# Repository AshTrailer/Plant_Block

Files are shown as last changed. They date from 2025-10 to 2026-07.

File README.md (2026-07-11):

# Plant Block - 智能植物养护系统 / Intelligent Plant Care System

[]()
[]()
[]()
[]()

基于 ESP32 的环境监测与自动控制系统，支持通风、补光、TEC 温控、浇水等核心功能，具备本地串口调试、云端 MQTT 远程监控能力。

*An ESP32-based environmental monitoring and automatic control system, supporting ventilation, supplemental lighting, TEC temperature control, watering, and other core functions, with local serial debugging and cloud MQTT remote monitoring capabilities.*

---

## 项目升级日志 / Project Update Log

### 🔧 最新更新 — 第二版原理图设计完成 / Latest: v2.0 Schematic Design Completed

第二版原理图绘制、焊盘及封装绘制已全部完成。电源架构与功能模块方案已最终确定，详见下方第二版硬件设计章节。PCB 布局布线为下一阶段工作。

*The v2.0 schematic, footprint, and PCB library have been completed. The power architecture and functional module design have been finalized — see the v2.0 hardware design section below. PCB layout is the next phase.*

### 2026年4月15日更新 — 第二版开发预告 / Apr 15, 2026 — v2.0 Development Preview

第二版硬件规划启动，将进行多项重大升级，提升系统性能和扩展性。

*v2.0 hardware planning initiated, featuring major upgrades to improve system performance and scalability.*

### 2026年3月更新 — 第一版完成 / Mar 2026 — v1.0 Completed

第一版硬件已完成设计、打样，软件核心功能开发完毕，升级为 4 通道版本。

*v1.0 hardware design, fabrication, and core software development completed; upgraded to a 4-channel version.*

---

## 第一版硬件设计 (v1.0) / v1.0 Hardware Design

> **设计思路 / Design Philosophy**：第一版以"多通道独立控制"为核心，目标是同时管理 4 个独立植物模块，每个模块配备独立的 LED 补光与传感器接口。12V 供电、单级降压的简洁架构便于快速验证核心功能。

> *v1.0 centered on "multi-channel independent control," aiming to manage 4 separate plant modules simultaneously, each with independent LED lighting and sensor interfaces. The simple 12V single-stage buck architecture enabled rapid core functionality validation.*

### 硬件架构 / Hardware Architecture

#### 电源系统 / Power System输入 / Input：12V DC
├── TPS54302DDCR：12V → 5V 降压转换 / Buck Converter\
├── PT4115：LED 恒流驱动 ×4 / Constant Current LED Driver ×4\
└── 各模块供电分配 / Peripheral Power Distribution

#### 控制通道配置 / Control Channel Configuration

| 模块类型 / Module Type | 设计预留 / Designed | 实际可用 / Available | 原因说明 / Note |
|---|---|---|---|
| **光照控制 / Lighting** | 4 通道 / ch | 4 通道 / ch | 每通道 3W，总计 12W / 3W per ch, 12W total |
| **水泵控制 / Water Pump** | 4 个 | 1 个 | PCB GPIO 端口分配错误 / GPIO assignment error |
| **传感器接口 / Sensor** | 4 个 | 1 个 | PCB GPIO 端口分配错误 / GPIO assignment error |

#### 核心功能模块 / Core Functional Modules

| # | 模块 / Module | 说明 / Description |
|---|---|---|
| 1 | **通风控制 / Ventilation** | 定时启停风扇 / Timed fan on/off |
| 2 | **补光灯控制 / Lighting** | PWM 智能调光（自动渐亮/渐暗）/ PWM dimming with auto fade |
| 3 | **LED 散热控制 / LED Cooling** | 独立散热管理 / Independent thermal management |
| 4 | **智能浇水 / Watering** | 土壤湿度阈值、4 小时防重复、周计划管理 / Soil moisture threshold, 4h anti-repeat, weekly schedule |
| 5 | **时间管理 / Time** | 软件计时、Unix 时间戳、ISO 周数、星期计算 / Software timer, Unix timestamp, ISO week, weekday calc |
| 6 | **命令解析器 / CLI** | 非阻塞串口命令，完整调试接口 / Non-blocking serial command parser |
| 7 | **云端通信 / Cloud** | WiFi + MQTT over TLS（状态上报、远程命令、遗嘱消息）/ Status report, remote command, LWT |
| 8 | **数据处理 / Data** | 去极值、均值、标准差、稳定性判断 / Outlier removal, mean, stddev, stability check |

> **注 / Note**：串口屏交互功能暂未开发，将在后续版本中实现。
> *The serial touchscreen UI is not yet developed and will be implemented in a future version.*

#### 硬件图片 / Hardware Images

<div align="center">
  v1.0 PCB Front / 第一版电路板正面
  <br/><em>第一版电路板正面 / v1.0 PCB Front View</em>
</div>

<div align="center">
  System Block Diagram / 系统框图
  Electrical Components / 电气组件图
  <br/><em>左：系统框图 / Left: System Block Diagram &nbsp;|&nbsp; 右：电气组件图 / Right: Electrical Components</em>
</div>

#### 第一版小结 / v1.0 Summary

| 维度 / Aspect | 状态 / Status |
|---|---|
| **硬件 / Hardware** | Cadence 原理图、封装、初版 PCB 已完成并打样，等待测试 / Schematic, footprint, PCB designed & fabricated, awaiting test |
| **软件 / Software** | 核心功能已完成，升级为 4 通道版本 / Core functions complete, 4-channel support |
| **已知问题 / Known Issues** | GPIO 端口分配错误导致部分通道不可用；12V 供电限制了 TEC 等大功率模块的引入 / GPIO assignment errors; 12V limits high-power modules like TEC |

---

## 第二版硬件设计 (v2.0) / v2.0 Hardware Design

> **设计思路 / Design Philosophy**：第二版从"多通道简单控制"转向"单系统精细化控制"。核心变化包括：① 提升输入电压至 24V 以支持更大功率负载；② 引入 TEC 半导体制冷实现主动温控；③ 使用 50W COB 灯珠替代 4 颗分立 LED，简化光路并提升光效；④ 增加多种传感器实现全方位环境感知；⑤ 增加硬件级过温保护，提升系统安全性。

> *v2.0 shifts from "multi-channel simple control" to "single-system precision control." Key changes: ① 24V input to support higher power loads; ② TEC-based active cooling; ③ 50W COB LED replaces 4 discrete LEDs for simplified optics and higher efficiency; ④ multi-sensor fusion for comprehensive environmental awareness; ⑤ hardware-level over-temperature protection for improved safety.*

---

### 2.1 电源架构 / Power Architecture

#### 电源树 / Power Tree
24V DC 输入 / Input\
│\
├── [保护电路 / Protection]\
│   ├── 防反接 / Reverse Polarity Protection\
│   ├── 防静电 (ESD) / ESD Protection\
│   └── 防浪涌 / Surge Protection\
│\
├── TPS56A37 ────────────► 12V @ 3A+ ────┬── 蠕动泵 / Peristaltic Pump (SI2302)\
│   (24V → 12V Buck)                      ├── TEC 冷端风扇 / TEC Cold-side Fan (SI2302)\
│                                         ├── 通风风扇 / Ventilation Fan (SI2302)\
│                                         └── 水冷风扇 / Water-cooling Fan (SI2302)\
│\
├── TPS54302DDCR ────────► 5V @ 2A+ ────┬── ESP32-WROOM-32E-N8(24V → 5V Buck)\
│                                       ├── CH340C (USB-UART)\
│                                       ├── DS18B20 ×2 (One Wire)\
│                                       ├── SHT30 (I²C)\
│                                       ├── 浮球开关 / Float Switch\
│                                       ├── IR2104STRPBF ×2 (TEC 半桥驱动)\
│                                       └── LM393DT ×2 (PT100 比较器)\
│\
└── AMS1117-3V3 ─────────► 3.3V ────────► ESP32 内核及 GPIO / ESP32 Core & GPIO
(5V → 3.3V LDO)

#### 电源芯片选型对比 / Power IC Selection

| 功能 / Function | 芯片 / IC | 输入范围 / Input | 输出 / Output | 说明 / Note |
|---|---|---|---|---|
| 24V → 12V Buck | **TPS56A37** | 4.5V – 28V | 12V / 3A+ | 同步降压，高效率 / Synchronous buck, high efficiency |
| 24V → 5V Buck | **TPS54302DDCR** | 4.5V – 28V | 5V / 2A+ | 与第一版同型号，输入范围满足 24V / Same IC as v1.0, input range covers 24V |
| 5V → 3.3V LDO | **AMS1117-3V3** | up to 15V | 3.3V / 1A | 经典低压差线性稳压器 / Classic low-dropout regulator |

#### 保护电路详情 / Protection Circuit Details

| 保护类型 / Protection | 实现方式 / Implementation | 防护对象 / Target |
|---|---|---|
| **防反接 / Reverse Polarity** | PMOS / 肖特基二极管方案 | 全部后端电路 / All downstream circuits |
| **防静电 / ESD** | TVS 二极管阵列（24V 输入端 + USB 信号线） | 电源入口及敏感信号引脚 |
| **防浪涌 / Surge** | TVS 管 + 共模电感 + π 型滤波 | 电源入口，抑制瞬态过压 |

---

### 2.2 功能模块详述 / Functional Modules

#### 2.2.1 蠕动泵控制 / Peristaltic Pump Control

| 参数 / Parameter | 规格 / Specification |
|---|---|
| **供电电压 / Voltage** | 12V DC |
| **驱动方式 / Drive** | **SI2302** N-MOSFET 低端开关 / Low-side switch |
| **控制接口 / Control** | ESP32 GPIO → SI2302 Gate（带栅极下拉电阻 / with gate pull-down） |
| **PWM 调速** | 支持 / Supported（软件可调流量 / software-adjustable flow rate） |
| **续流保护 / Flyback** | 肖特基二极管并联泵电机 / Schottky diode across pump motor |

#### 2.2.2 风扇控制（3 路）/ Fan Control (3 Channels)

三路风扇均采用统一驱动方案，仅控制 GPIO 不同：

*All 3 fan channels use the same driver topology with different control GPIOs:*

| 风扇 / Fan | 用途 / Purpose | 供电 / Voltage | 驱动 MOSFET |
|---|---|---|---|
| **TEC 冷端风扇** / Cold-side Fan | 为 TEC 冷端散热器强制通风 / Force air over TEC cold-side heatsink | 12V | SI2302 |
| **通风风扇** / Ventilation Fan | 培养空间空气交换 / Grow space air exchange | 12V | SI2302 |
| **水冷风扇** / Water-cooling Fan | TEC 热端水冷排散热 / Radiator cooling for TEC hot-side | 12V | SI2302 |

#### 2.2.3 浮球开关 / Float Switch (液位检测 / Water Level Detection)

| 参数 / Parameter | 规格 / Specification |
|---|---|
| **类型 / Type** | 机械浮球开关 / Mechanical float switch（常开/常闭可选 / NO/NC selectable） |
| **接口 / Interface** | GPIO 数字输入 + 上拉电阻 / GPIO digital input with pull-up |
| **功能 / Function** | 水箱低液位检测，防止泵空转 / Low water level detection to prevent pump dry-running |
| **软件处理 / Software** | 低液位触发中断 → 停止蠕动泵 + MQTT 报警 / Low level interrupt → stop pump + MQTT alert |

#### 2.2.4 DS18B20 温度传感器 ×2 / Dual DS18B20 Temperature Sensors

| 参数 / Parameter | 规格 / Specification |
|---|---|
| **总线类型 / Bus** | **One Wire（单总线）**，两颗传感器共享同一 GPIO / Shared single GPIO |
| **传感器 1** | TEC 冷端温度 / TEC cold-side temperature |
| **传感器 2** | TEC 热端温度 / TEC hot-side temperature |
| **分辨率 / Resolution** | 9–12 bit 可配置 / configurable（默认 12 bit / default 12 bit） |
| **供电方式 / Power** | 寄生供电模式 / Parasite power mode（VDD 接 GND）或外部供电 |
| **识别方式 / ID** | 通过唯一 64-bit ROM ID 区分两颗传感器 / Distinguished by unique 64-bit ROM ID |

> **设计说明 / Design Note**：两颗 DS18B20 共享单个 GPIO 可节省 ESP32 引脚资源。软件通过 ROM ID 分别读取冷端和热端温度，用于 TEC PID 控制算法的反馈输入。
> *Sharing a single GPIO conserves ESP32 pins. Firmware distinguishes sensors by ROM ID for cold/hot side temperature feedback into the TEC PID control loop.*

#### 2.2.5 SHT30 温湿度传感器 / SHT30 Temperature & Humidity Sensor

| 参数 / Parameter | 规格 / Specification |
|---|---|
| **芯片 / IC** | SHT30-DIS（I²C 接口） |
| **测量范围 / Range** | 温度 / Temp：-40°C ~ +125°C；湿度 / Humidity：0% ~ 100% RH |
| **精度 / Accuracy** | 温度 / Temp：±0.3°C；湿度 / Humidity：±2% RH（典型值 / typical） |
| **接口 / Interface** | I²C（SCL + SDA），3.3V 供电 |
| **用途 / Purpose** | 培养空间环境温湿度监测 / Ambient temp & humidity monitoring in grow space |

#### 2.2.6 50W COB 灯珠驱动 / 50W COB LED Driver

| 参数 / Parameter | 规格 / Specification |
|---|---|
| **LED 类型 / Type** | 50W COB（Chip-on-Board）灯珠，全光谱 / Full-spectrum |
| **驱动芯片 / Driver IC** | **XL6005E1** — Boost 升压恒流驱动 / Boost constant-current driver |
| **调光方式 / Dimming** | **PWM 调光**，ESP32 GPIO 输出 PWM 至 XL6005E1 EN/DIM 引脚 |
| **调光频率 / PWM Freq** | 建议 1kHz – 20kHz（避开人耳敏感频段 / avoid audible range） |
| **散热策略 / Cooling** | COB 灯珠独立散热片 + 通风风扇辅助 / Dedicated heatsink + ventilation fan |

> **设计说明 / Design Note**：相比第一版的 4 路 PT4115 + 3W 分立 LED，第二版采用单颗 50W COB + XL6005E1 Boost 方案。优势：① 光效更高；② 光谱均匀性更好；③ 简化 PCB 布线（单通道 vs 四通道）；④ 减少元器件数量。
> *Compared to v1.0's 4× PT4115 + 3W discrete LEDs, v2.0 uses a single 50W COB + XL6005E1 boost topology. Advantages: higher efficacy, better spectral uniformity, simplified PCB routing (1ch vs 4ch), and reduced BOM count.*

#### 2.2.7 TEC H 桥控制电路 / TEC H-Bridge Control

这是第二版最核心的新增模块，用于驱动 TEC 半导体制冷片实现双向温控（加热/制冷）。

*This is the most critical new module in v2.0, driving the TEC (Peltier) module for bidirectional temperature control (heating/cooling).*

| 组件 / Component | 型号 / Part | 数量 / Qty | 功能 / Function |
|---|---|---|---|
| **TEC 模块 / TEC Module** | TEC1-12706 | 1 | 12V / 6A max，实际 ≤3A |
| **半桥驱动 / Half-bridge Driver** | **IR2104STRPBF** | 2 | 自举高侧驱动 / Bootstrap high-side driver |
| **H 桥 MOSFET** | **IRFZ44NS** | 4 | N-MOSFET，55V/49A，低 Rds(on) |
| **自举电容 / Bootstrap Cap** | 10µF–22µF 瓷片 | 2 | 为高侧 MOSFET 提供栅极驱动电压 |
| **自举二极管 / Bootstrap Diode** | 快恢复二极管 / Fast recovery | 2 | 自举电容充电通路 |

| 设计要点 / Design Point | 详情 / Detail |
|---|---|
| **死区时间 / Dead Time** | 软件控制，防止上下管直通 / Software-controlled to prevent shoot-through |
| **开关频率 / Switching Freq** | 建议 20kHz–50kHz PWM / Recommended 20kHz–50kHz PWM |
| **仿真验证 / Simulation** | 已通过 **LTspice** 仿真验证 H 桥开关波形及自举电路工作正常 |
| **电流采样 / Current Sense** | 可选：H 桥低端串联采样电阻 + 差分放大器 → ESP32 ADC |

> **LTspice 仿真已通过** — H 桥开关时序、自举电容充放电、死区保护逻辑均已仿真验证。
> *LTspice simulation passed — H-bridge switching timing, bootstrap capacitor charging, and dead-time protection have been verified.*

#### 2.2.8 PT100 过温断电电路 / PT100 Over-Temperature Shutdown

独立于 MCU 的硬件级过温保护，当 TEC 或 COB LED 区域温度异常升高时自动切断电源。

*Hardware-level over-temperature protection independent of the MCU — automatically cuts power if TEC or COB LED area temperature rises abnormally.*

| 组件 / Component | 型号 / Part | 数量 / Qty | 功能 / Function |
|---|---|---|---|
| **温度传感器 / Temp Sensor** | PT100 铂电阻 / Platinum RTD | 1 | 温度 → 电阻变化 / Temperature → resistance |
| **比较器 / Comparator** | **LM393DT** | 2 | 双路比较器，提供窗口比较 / Dual comparator for window comparison |
| **基准电压 / Reference** | 电阻分压或 TL431 | 1 | 设定过温阈值 / Sets over-temp threshold |

Q1/Q3 由 IR2104 #1 驱动 / driven by IR2104 #1
Q2/Q4 由 IR2104 #2 驱动 / driven by IR2104 #2

方向控制 / Direction Control:

Q1+Q4 导通 → TEC 正向电流 → 制冷模式 / Cooling
Q2+Q3 导通 → TEC 反向电流 → 加热模式 / Heating
PWM 占空比调节 → 功率控制 / Power modulation
PT100 过温断电电路原理 / Over-Temp Shutdown Principle:

PT100 ──► 惠斯通电桥 / Wheatstone Bridge ──► LM393DT #1 (上限比较 / Upper threshold)
──► LM393DT #2 (下限比较 / Lower threshold)
│
比较器输出 / Comparator Out ──► MOSFET 切断主电源
Cut main power via MOSFET

| 设计要点 / Design Point | 详情 / Detail |
|---|---|
| **阈值设定 / Threshold** | 通过分压电阻设定，如 80°C 触发断电 / Set via resistor divider, e.g., 80°C trip point |
| **滞回 / Hysteresis** | 正反馈电阻实现滞回，防止临界温度反复开关 / Positive feedback resistor prevents oscillation near threshold |
| **独立性 / Independence** | 纯硬件电路，ESP32 死机/复位不影响保护功能 / Pure hardware — protection works even if ESP32 crashes |
| **输出 / Output** | 比较器输出驱动 MOSFET 或继电器切断 24V 主干路 |

#### 2.2.9 MCU 及编程接口 / MCU & Programming Interface

| 参数 / Parameter | 规格 / Specification |
|---|---|
| **主控 / MCU** | **ESP32-WROOM-32E-N8**（8MB Flash，WiFi + BLE） |
| **USB 转串口 / USB-UART** | **CH340C** |
| **USB 接口 / USB Connector** | **USB-C**（支持烧录与串口通信 / programming & serial） |
| **自动下载电路 / Auto-Download** | EN + IO0 自动时序控制（DTR/RTS → 三极管/MOSFET） |
| **备用烧录 / Alt Programming** | 排母/排针引出 TX/RX/EN/IO0/GND，可外接 USB-UART 模块 |
| **按键 / Buttons** | RESET + BOOT（IO0）按键，支持手动进入下载模式 |
自动下载电路原理 / Auto-Download Circuit:

CH340C DTR ──► 电容耦合 ──► ESP32 EN
CH340C RTS ──► 电容耦合 ──► ESP32 IO0

当 esptool/platformio 发起下载时，DTR/RTS 自动产生复位 + 进入下载模式的时序。
When esptool/platformio initiates flashing, DTR/RTS automatically generate
the reset + bootloader entry timing sequence.

---

### 2.3 原理图 / Schematics

#### 原理图一：电源架构及外设模块 / Schematic 1: Power Architecture& Peripherals

> **涵盖内容 / Coverage**：24V DC 输入保护（防反接/ESD/浪涌）→ TPS56A37 (24V→12V) → TPS54302DDCR (24V→5V) → AMS1117-3V3 (5V→3.3V)，各电压轨去耦电容及测试点。DS18B20 ×2 (One Wire) + SHT30 (I²C) + 浮球开关 + SI2302 ×4 (蠕动泵/3路风扇) + XL6005E1 COB LED 驱动

> *24V DC input protection (reverse polarity / ESD / surge) → TPS56A37 (24V→12V) → TPS54302DDCR (24V→5V) → AMS1117-3V3 (5V→3.3V), decoupling capacitors and test points for each rail.DS18B20 ×2 (One Wire) + SHT30 (I²C) + float switch + SI2302 ×4 (pump / 3× fans) + XL6005E1 COB LED driver.*

<div align="center">



*原理图一：电源架构及外设模块 / Schematic 1: Power Architecture& Peripherals*

</div>

---


#### 原理图二：主控及TEC H 桥及过温保护 / Schematic 2: MCU & TEC H-Bridge & Over-Temp Protection

> **涵盖内容 / Coverage**：ESP32-WROOM-32E-N8 + CH340C + USB-C + 自动下载电路 + 按键电路 + IR2104STRPBF ×2 半桥驱动 + IRFZ44NS ×4 H 桥 MOSFET + TEC 接口 + 自举电路 + PT100 惠斯通电桥 + LM393DT ×2 窗口比较器 + 过温断电输出。

> *ESP32-WROOM-32E-N8 + CH340C + USB-C + auto-download circuit + buttons + IR2104STRPBF ×2 half-bridge drivers + IRFZ44NS ×4 H-bridge MOSFETs + TEC connector + bootstrap circuits + PT100 Wheatstone bridge + LM393DT ×2 window comparator + over-temp shutdown output.*

<div align="center">

*原理图二：主控及TEC H 桥及过温保护 / Schematic 2: MCU & TEC H-Bridge & Over-Temp Protection*

</div>

---

#### 原理图三：接口 / Schematic 3: Connector

> **涵盖内容 / Coverage**：各级接口。

> *Various of Connectors*

<div align="center">



*原理图三：接口 / Schematic 3: Connector*

</div>

---

### 2.4 第一版 → 第二版 设计演进对比 / v1.0 → v2.0 Design Evolution

以下对比表清晰展示了两个版本之间的设计思路变化：

*The following comparison clearly illustrates the design evolution between the two versions:*

| 维度 / Aspect | 第一版 v1.0 | 第二版 v2.0 | 变化说明 / Note |
|---|---|---|---|
| **输入电源 / Input** | 12V DC / 5A | **24V DC / 5A** | 提升电压减少电流损耗，适配 TEC 等大功率负载 |
| **电压轨 / Rails** | 12V → 5V（单级） | 24V → 12V → 5V → 3.3V（三级） | 分级供电，各电压轨独立稳压 |
| **24V→12V Buck** | — | **TPS56A37** | 新增，为 12V 设备供电 |
| **24V→5V Buck** | TPS54302DDCR (12V→5V) | **TPS54302DDCR** (24V→5V) | 同芯片，输入范围满足 24V |
| **5V→3.3V LDO** | — | **AMS1117-3V3** | 新增，ESP32 独立 3.3V 供电 |
| **输入保护 / Protection** | 基本 / Basic | **防反接 + ESD + 浪涌** | 全面提升可靠性 |
| **LED 照明 / Lighting** | 4× 3W 分立 LED + PT4115 | **1× 50W COB + XL6005E1** | 集成化、高光效、PWM 调光 |
| **TEC 温控 / TEC** | 无 / None | **TEC1-12706 + H 桥** | 核心新增功能，主动制冷/加热 |
| **H 桥驱动 / H-Bridge** | — | **IR2104STRPBF ×2 + IRFZ44NS ×4** | LTspice 仿真验证 |
| **过温保护 / OT Protection** | 无 / None | **PT100 + LM393DT ×2** | 硬件级独立保护 |
| **温度传感器 / Temp Sensor** | — | **DS18B20 ×2** (One Wire 共享 GPIO) | TEC 冷端 & 热端双点监测 |
| **温湿度传感器 / RH Sensor** | — | **SHT30** (I²C) | 环境温湿度监测 |
| **液位检测 / Water Level** | — | **浮球开关** | 水箱液位，防泵空转 |
| **水泵 / Pump** | 普通水泵（1 路可用） | **蠕动泵** (SI2302 驱动) | 更精确的流量控制 |
| **风扇控制 / Fan** | 通风风扇 | **3 路** (TEC冷端+通风+水冷) | 全部 12V / SI2302 NMOS |
| **MCU / 主控** | ESP32 | **ESP32-WROOM-32E-N8** | 8MB Flash，性能更稳定 |
| **USB 接口 / USB** | Micro-USB | **USB-C + CH340C** | 正反插，更可靠 |
| **自动下载 / Auto-DL** | 基础 / Basic | **DTR/RTS 自动下载电路** | 一键烧录 |
| **烧录方式 / Programming** | USB | **USB-C + 排母/排针** | 双通道烧录 |
| **PCB 层数 / PCB Layers** | 2 层 | **规划 4 层** | 改善信号完整性和 EMC |
| **软件适配 / Software** | 4 通道架构 | 需适配新硬件驱动 | TEC PID、多传感器融合等 |

---

### 2.5 软件功能规划 / Software Features Plan

第二版软件将在第一版基础上进行以下升级（具体实现待 PCB 完成后启动）：

*The v2.0 firmware will upgrade upon v1.0 with the following features (implementation begins after PCB completion):*

| 模块 / Module | 第一版 v1.0 | 第二版 v2.0 规划 / Plan |
|---|---|---|
| **TEC 控制 / TEC Control** | — | 双闭环 PID（温度环 + 电流环），冷/热端温差监控 |
| **COB 调光 / COB Dimming** | 4ch PWM 渐亮/渐暗 | 单通道高精度 PWM，模拟日出日落 |
| **传感器融合 / Sensor Fusion** | 土壤湿度 | DS18B20×2 + SHT30 + PT100 + 浮球开关 |
| **风扇策略 / Fan Strategy** | 定时 5min/55min | 温控自适应调速（TEC 冷端联动 + 环境通风联动） |
| **蠕动泵 / Pump** | 定时浇水 | 基于浮球开关 + 周计划精确浇水 |
| **云端通信 / Cloud** | WiFi + MQTT over TLS | 保持不变，扩展上报数据点 |
| **安全保护 / Safety** | — | PT100 过温断电 + 浮球低液位 + 看门狗 |
| **串口屏 / Touch UI** | 未开发 | 暂不开发，先定硬件再实现 |

---

### 2.6 当前进展 / Current Status

| 阶段 / Phase | 状态 / Status | 说明 / Note |
|---|---|---|
| **原理图绘制 / Schematic** |  已完成 | 三张原理图，涵盖电源/主控外设/TEC驱动 |
| **焊盘及封装 / Footprint & Library** | 已完成 | Cadence PCB 封装库建立完毕 |
| **LTspice 仿真 / Simulation** |  已通过 | TEC H 桥开关时序及自举电路仿真验证 |
| **PCB 布局布线 / PCB Layout** |  待进行 | 规划 4 层板设计 |
| **PCB 打样 / Fabrication** |  待进行 | — |
| **硬件调试 / Hardware Debug** |  待进行 | — |
| **软件适配 / Firmware** |  待进行 | 基于第一版代码重构，适配新硬件 |

---

## 项目持续开发中 / Project Under Active Development

Plant Block 项目将持续迭代升级，致力于打造更智能、更可靠的植物自动养护系统。欢迎关注项目进展并提出宝贵建议！

*The Plant Block project will continue to iterate and upgrade, striving to build a smarter and more reliable automatic plant care system. Follow the project and share your suggestions!*

> **项目状态 / Project Status**：
> - **v1.0**：硬件打样完成，核心软件功能开发完毕，待测试 / Hardware fabricated, core firmware complete, awaiting testing
> - **v2.0**：原理图及封装设计完成，待 PCB 布局布线 / Schematic & footprint design complete, PCB layout pending

---

## 开发环境 / Development Environment

| 类型 / Type | 工具 / Tool |
|---|---|
| **MCU 固件 / Firmware** | ESP-IDF / PlatformIO |
| **硬件设计 / Hardware** | Cadence (OrCAD / Allegro) |
| **电路仿真 / Simulation** | LTspice |
| **版本管理 / VCS** | Git + GitHub |
| **调试工具 / Debug** | 串口终端 (PuTTY / minicom) + MQTT 客户端 |

---

## 许可证 / License

MIT License

---

*README last updated: 2026年 / 保持更新*

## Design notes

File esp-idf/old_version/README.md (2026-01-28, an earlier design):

# Old Version (v1)

- Framework: PlatformIO
- Core: Arduino
- Target: ESP32
- Status: Frozen

This directory contains the original Arduino-based implementation.
Development continues in the esp-idf directory using ESP-IDF and ESP32-C6.

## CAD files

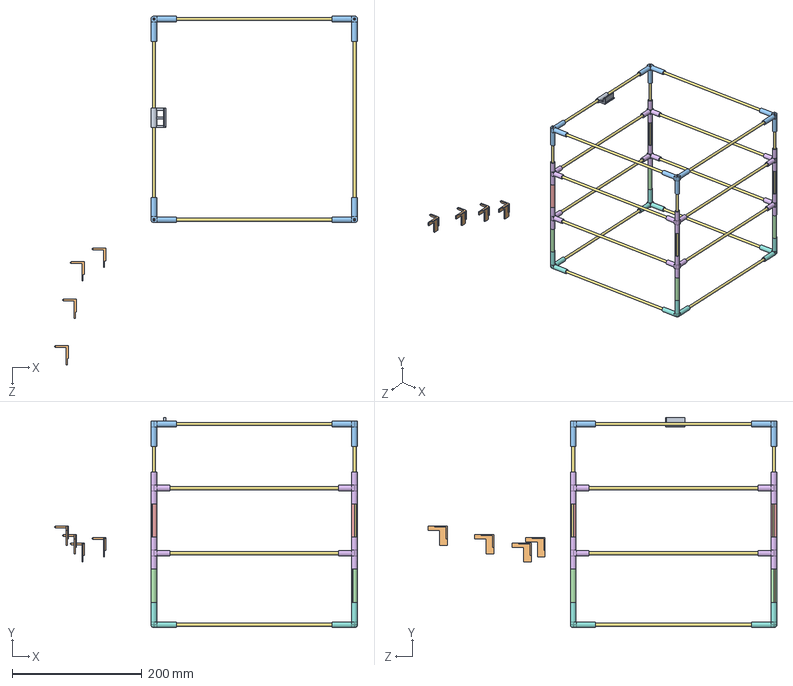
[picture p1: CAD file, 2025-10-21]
esp-idf/Block_Plant_Solidwork/Block_Assemb.SLDASM
467.2 x 324.2 x 537.5 mm
Corner x 4
Rob x 20
Mid_Edge x 8
Supprot_Rob x 4
Supprot_Rob_Buttom x 4
Upper_Corner_1 x 4
Upper_Corner_2 x 4
Upper_Mid_Corner_Left

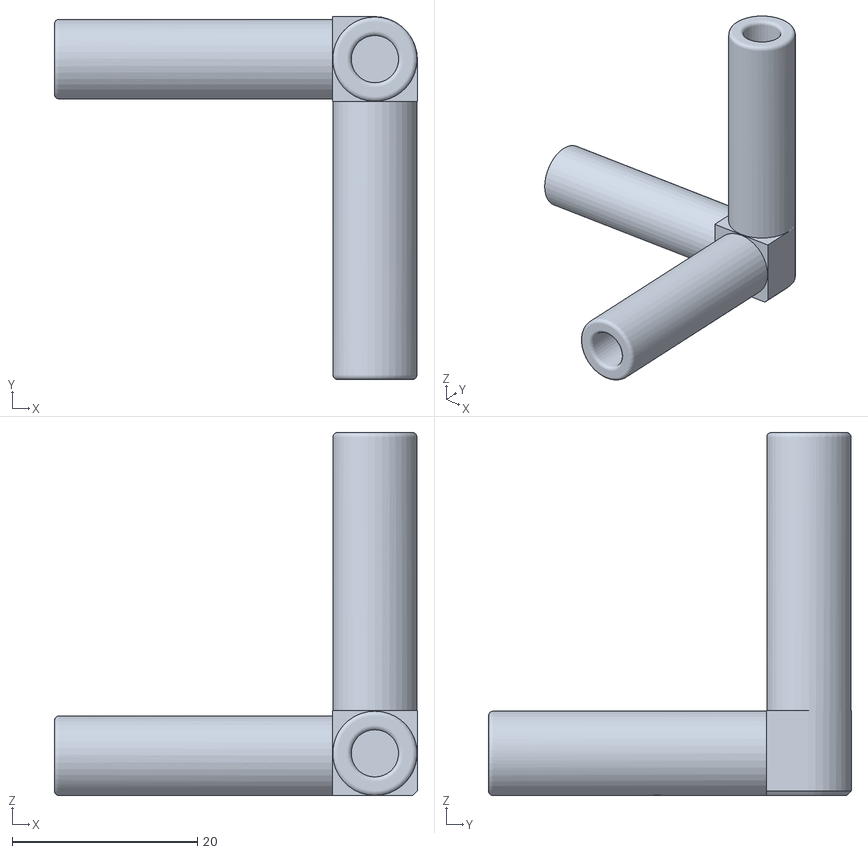
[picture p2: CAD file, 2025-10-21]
esp-idf/Block_Plant_Solidwork/Other_Connector_Engineering.STL
39.2 x 39.2 x 39.2

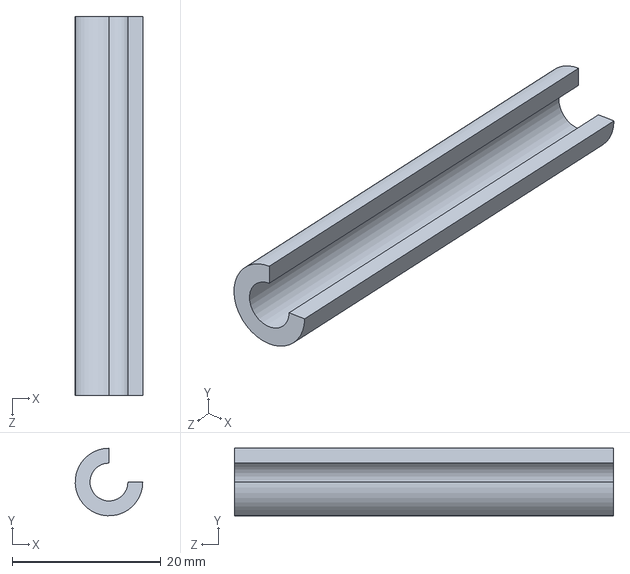
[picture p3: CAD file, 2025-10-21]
esp-idf/Block_Plant_Solidwork/Supprot_Rob_Buttom.SLDPRT
9.09 x 9.09 x 51.0 mm

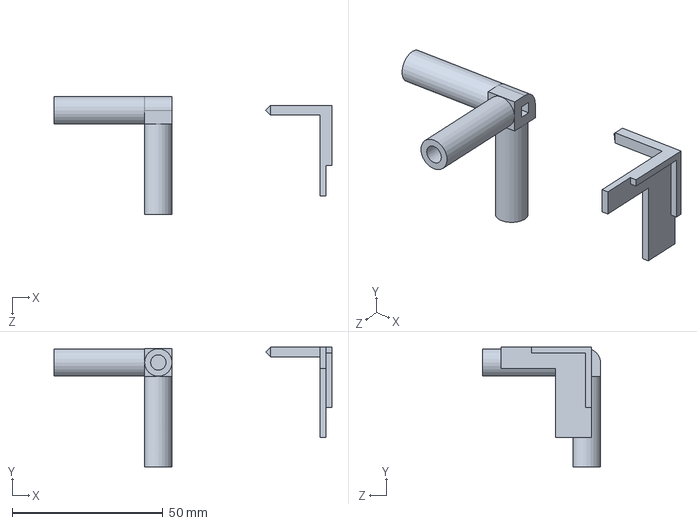
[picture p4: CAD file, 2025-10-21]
esp-idf/Block_Plant_Solidwork/Upper_Corner.SLDPRT
92.2 x 39.7 x 39.2 mm

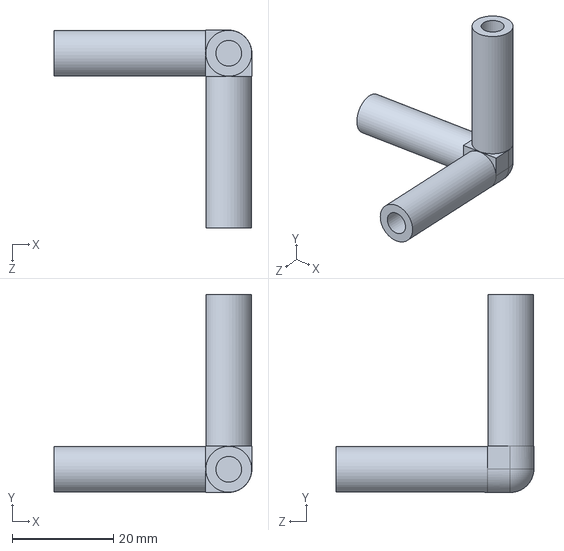
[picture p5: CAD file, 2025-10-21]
esp-idf/Block_Plant_Solidwork/Corner.SLDPRT
39.2 x 39.2 x 39.2 mm

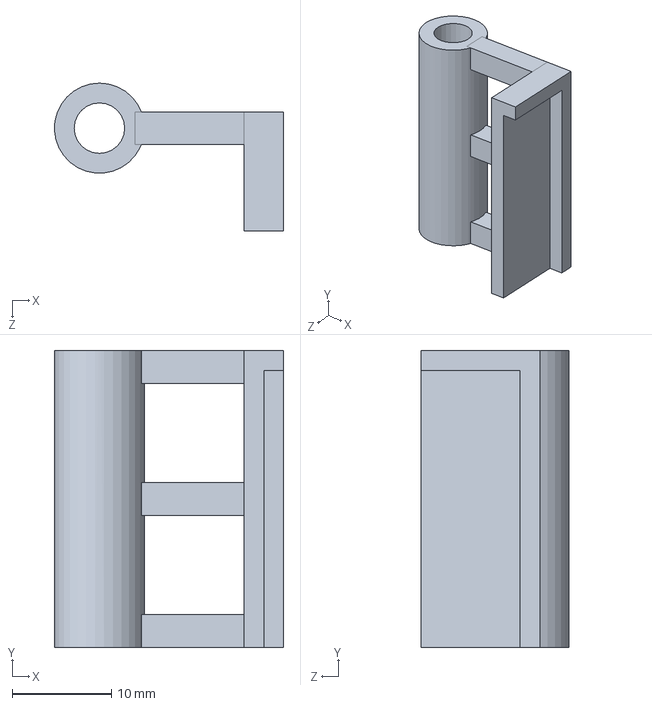
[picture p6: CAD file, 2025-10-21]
esp-idf/Block_Plant_Solidwork/Upper_Mid_Corner_Right.SLDPRT
23.1 x 30.0 x 14.9 mm

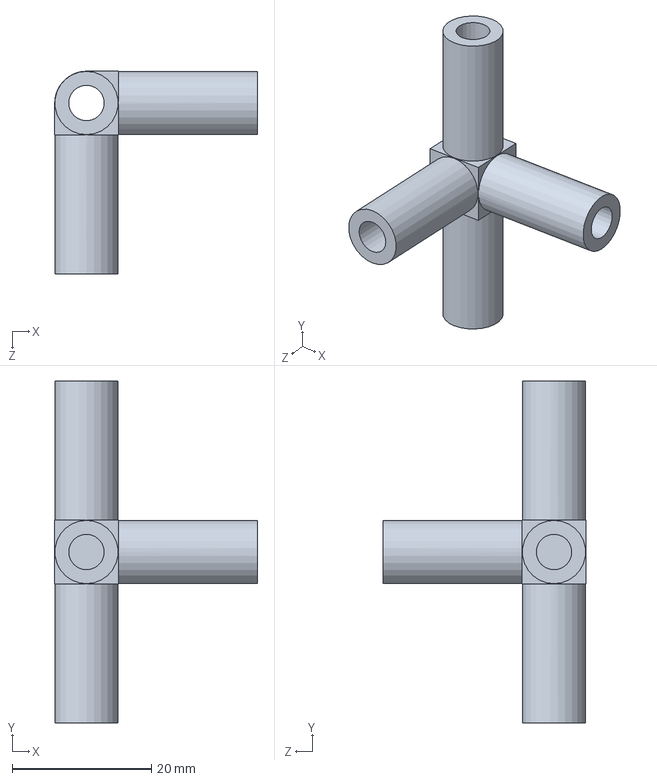
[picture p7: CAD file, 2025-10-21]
esp-idf/Block_Plant_Solidwork/Mid_Edge.SLDPRT
29.2 x 49.2 x 29.2 mm

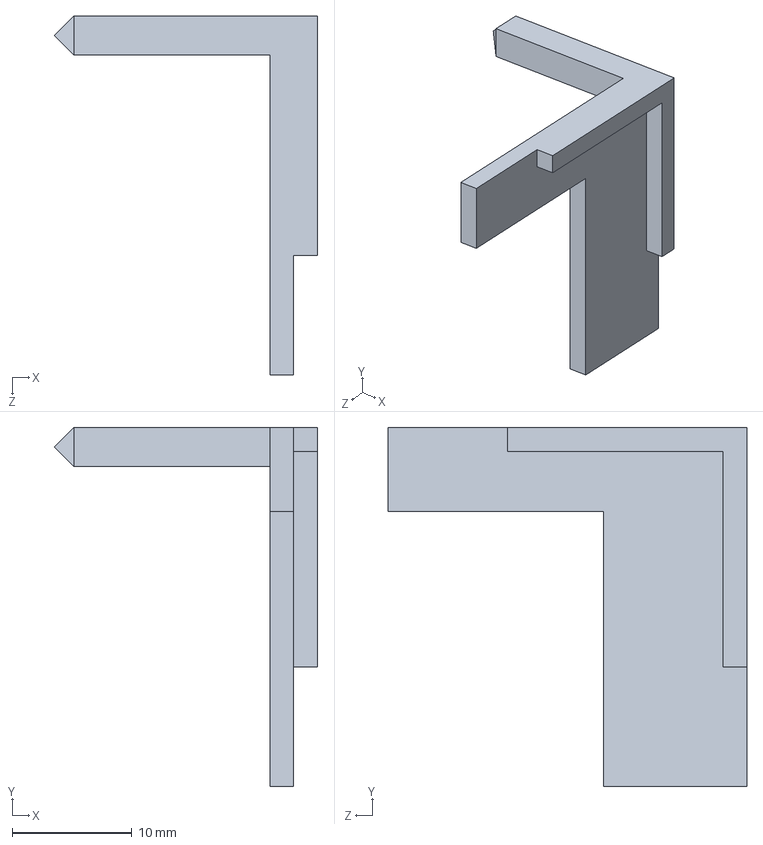
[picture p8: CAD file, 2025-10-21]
esp-idf/Block_Plant_Solidwork/Upper_Corner_2.SLDPRT
22.0 x 30.0 x 30.0 mm

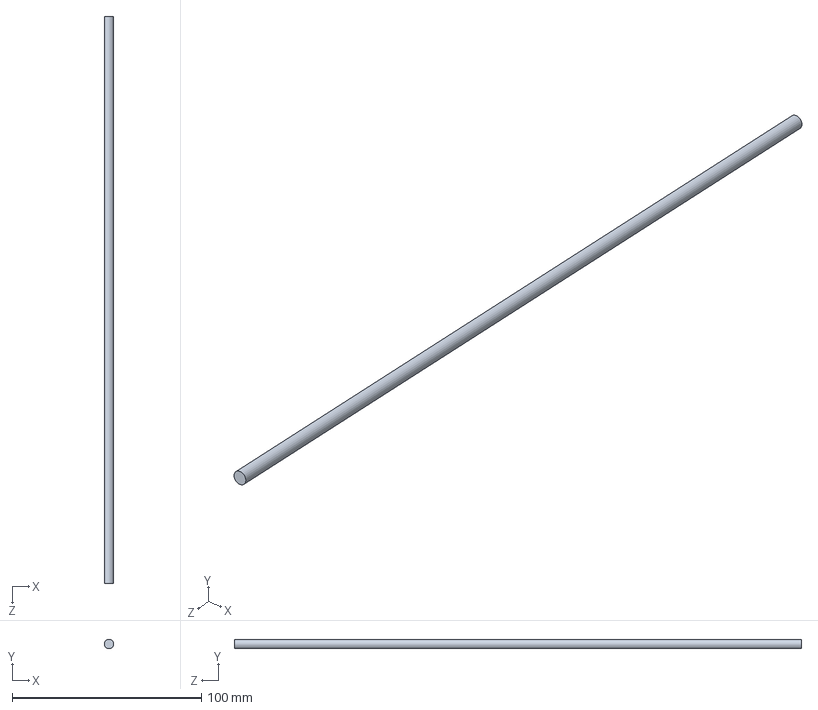
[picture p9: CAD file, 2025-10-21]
esp-idf/Block_Plant_Solidwork/Rob.SLDPRT
5.00 x 5.00 x 300.0 mm

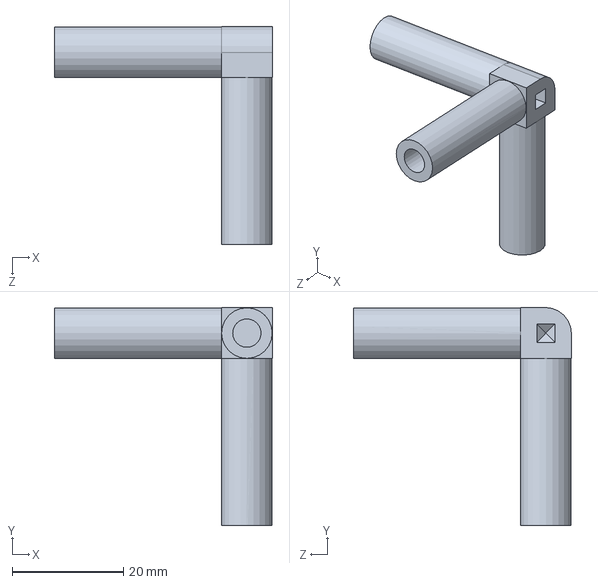
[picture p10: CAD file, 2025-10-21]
esp-idf/Block_Plant_Solidwork/Upper_Corner_1.SLDPRT
39.2 x 39.2 x 39.2 mm

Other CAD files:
esp-idf/Block_Plant_Solidwork/Upper_Mid_Corner_Left.SLDPRT
esp-idf/Block_Plant_Solidwork/Supprot_Rob.SLDPRT
esp-idf/Block_Plant_Solidwork/Connector.SLDPRT
esp-idf/Block_Plant_Solidwork/Connector.STL

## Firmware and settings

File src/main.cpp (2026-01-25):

#include <Arduino.h>
#include <DHT.h>
#include <Wire.h>
#include <U8x8lib.h>
#include <Ds1302.h>

#define PUMP_PIN_1 26
#define PUMP_PIN_2 25

#define PIN_SDA 22
#define PIN_SCL 23

#define PIN_SOILSENSOR_1 32
#define PIN_SOILSENSOR_2 33

#ifndef PIN_ENA
#define PIN_ENA 21
#define PIN_DAT 19
#define PIN_CLK 18
#endif

#define LINE_WIDTH 16

#define DHTPIN 5
#define DHTTYPE DHT11

const char* menuItems[] = {"Data", "SetTime"};
int menuSize = sizeof(menuItems) / sizeof(menuItems[0]);

const int BUTTON1_PIN = 17;
const int BUTTON2_PIN = 16;
const int BUTTON3_PIN = 4;
const int BUTTON4_PIN = 15;
const unsigned long BUTTON4_DEBOUNCE_MS = 50;
const unsigned long BUTTON4_REPEAT_MS   = 200;

enum ButtonMode {
  BUTTON_TOGGLE,
  BUTTON_HOLD,
  BUTTON_PULSE,
  BUTTON_REPEAT
};

U8X8_SSD1306_128X64_NONAME_HW_I2C u8x8(U8X8_PIN_NONE);

class RTCManager {
private:
  Ds1302 rtc;
  uint8_t lastSecond;

  static const char* WeekDays[7];

public:
  RTCManager(uint8_t pinCE, uint8_t pinCLK, uint8_t pinDAT)
    : rtc(pinCE, pinCLK, pinDAT), lastSecond(255) {}

  void begin() {
    rtc.init();

    if (rtc.isHalted()) {
      Serial.println("Setting default time...");
      Ds1302::DateTime dt;
      dt.year   = 25;
      dt.month  = 11;
      dt.day    = 18;
      dt.hour   = 19;
      dt.minute = 18;
      dt.second = 30;
      dt.dow    = 4;

      rtc.setDateTime(&dt);
    }
}

void printIfSecondChanged() {
  Ds1302::DateTime now;
  rtc.getDateTime(&now);

  if (now.second != lastSecond) {
    lastSecond = now.second;
    printTime(now);
  }
}

void getDateTime(Ds1302::DateTime &dt) {
        rtc.getDateTime(&dt);
}

bool getFormattedDate(char *buf, size_t size) {
  Ds1302::DateTime now;
  rtc.getDateTime(&now);
  if (now.second != lastSecond) {
    lastSecond = now.second;
    snprintf(buf, size, "20%02d/%02d/%02d", now.year, now.month, now.day);
    return true; 
  }
  return false;
}

bool getFormattedDateTime(char *bufDate, size_t sizeDate,
                          char *bufTime, size_t sizeTime) {
  Ds1302::DateTime now;
  rtc.getDateTime(&now);

  if (now.second != lastSecond) {
    lastSecond = now.second;
    snprintf(bufDate, sizeDate, "20%02d/%02d/%02d", now.year, now.month, now.day);
    snprintf(bufTime, sizeTime, "%02d:%02d:%02d", now.hour, now.minute, now.second);
    return true;
  }
  return false;
}

bool getFormattedMonthDayTime(char *buf, size_t size) {
  Ds1302::DateTime now;
  rtc.getDateTime(&now);
  if (now.second != lastSecond) {
    lastSecond = now.second;
    snprintf(buf, size, "%02d/%02d %02d:%02d:%02d",
              now.month, now.day, now.hour, now.minute, now.second);
    return true;
  }
  return false;
}

void setDateTime(const Ds1302::DateTime &dt) {
  Ds1302::DateTime temp = dt;
  rtc.setDateTime(&temp);
}

private:
  void printTime(const Ds1302::DateTime& now) {
    Serial.print("20");
    if (now.year < 10) Serial.print('0');
    Serial.print(now.year);
    Serial.print('-');
    if (now.month < 10) Serial.print('0');
    Serial.print(now.month);
    Serial.print('-');
    if (now.day < 10) Serial.print('0');
    Serial.print(now.day);
    Serial.print(' ');
    Serial.print(WeekDays[now.dow - 1]);
    Serial.print(' ');
    if (now.hour < 10) Serial.print('0');
    Serial.print(now.hour);
    Serial.print(':');
    if (now.minute < 10) Serial.print('0');
    Serial.print(now.minute);
    Serial.print(':');
    if (now.second < 10) Serial.print('0');
    Serial.print(now.second);
    Serial.println();
  }
};
const char* RTCManager::WeekDays[7] = {
    "Monday", "Tuesday", "Wednesday", "Thursday", "Friday", "Saturday", "Sunday"
};
RTCManager rtcManager(PIN_ENA, PIN_CLK, PIN_DAT);

class SoilSensor {
private:
    uint8_t pin;
    uint8_t displayRow;
    U8X8_SSD1306_128X64_NONAME_HW_I2C &display;

    unsigned long lastSampleTime;
    unsigned long lastUpdateTime;

    float voltageSum;
    uint16_t sampleCount;

    float lastVoltage;
    float lastMoisture;
    bool valid;

    const float a = -1.176;
    const float b = 1.77;
    const float moistureError = 8.0f; // ±8%

public:
  SoilSensor(uint8_t p, uint8_t row, U8X8_SSD1306_128X64_NONAME_HW_I2C &disp)
      : pin(p), displayRow(row), display(disp),
        lastSampleTime(0), lastUpdateTime(0),
        voltageSum(0), sampleCount(0),
        lastVoltage(0), lastMoisture(0),
        valid(false)
  {}

  void begin() {
    pinMode(pin, INPUT);
  }

  void update(bool showOnOLED) {
    unsigned long now = millis();
    if (now - lastSampleTime >= 1000) {
      lastSampleTime = now;
      int raw = analogRead(pin);
      float v = raw * 3.0f / 4095.0f;
      voltageSum += v;
      sampleCount++;
    }

    if (now - lastUpdateTime >= 5000) {
      lastUpdateTime = now;
      if (sampleCount > 0) {
        lastVoltage = voltageSum / sampleCount;
        voltageSum = 0;
        sampleCount = 0;

        float h = (lastVoltage - b) / a;
        if (h < 0) h = 0;
        if (h > 1) h = 1;
        lastMoisture = h * 100.0f;
        valid = true;
      }
      if (showOnOLED) displayLast();
      }
  }

  float getLatestMoisture() const {
    return valid ? lastMoisture : NAN;
  }

  void displayLast() {
    char buf[20];
    snprintf(buf, sizeof(buf),
            "M%d: %.1f%% (%.0f%%)",
            (displayRow - 2),
            lastMoisture,
            moistureError);
    display.drawString(0, displayRow, buf);
  }

  float getMoisture() const { return lastMoisture; }
  bool hasValid() const { return valid; }
};

class Button {
  public:
    Button(int pin, ButtonMode mode, unsigned long debounce = 20, unsigned long repeatInterval = 500)
      : _pin(pin), _mode(mode), _debounce(debounce), _repeatInterval(repeatInterval),
        _lastState(HIGH), _buttonState(HIGH), _lastDebounceTime(0),
        _output(false), _lastOutputTime(0) {
      pinMode(pin, INPUT_PULLUP);
    }

    bool update() {
      bool reading = digitalRead(_pin);

      debounceCheck(reading);

      if ((millis() - _lastDebounceTime) > _debounce) {
        bool lastLogic = _buttonState;
        _buttonState = reading;

        switch (_mode) {
          case BUTTON_TOGGLE:
            handleToggle(lastLogic);
            break;

          case BUTTON_HOLD:
            handleHold();
            break;

          case BUTTON_PULSE:
            handlePulse(lastLogic);
            break;

          case BUTTON_REPEAT:
            handleRepeat();
            break;
        }
      }

      _lastState = reading;
      return _output;
    }

  private:
    int _pin;
    ButtonMode _mode;
    unsigned long _debounce;
    unsigned long _repeatInterval;

    bool _lastState;
    bool _buttonState;
    unsigned long _lastDebounceTime;

    bool _output;
    unsigned long _lastOutputTime;

    void debounceCheck(bool reading) {
      if (reading != _lastState) {
        _lastDebounceTime = millis();
      }
    }

    void handleToggle(bool lastLogic) {
      if (lastLogic == HIGH && _buttonState == LOW) {
        _output = !_output;
      }
    }

    void handleHold() {
      _output = (_buttonState == LOW);
    }

    void handlePulse(bool lastLogic) {
      _output = (lastLogic == HIGH && _buttonState == LOW);
    }

    void handleRepeat() {
      if (_buttonState == LOW) {
        if (millis() - _lastOutputTime >= _repeatInterval) {
          _output = true;
          _lastOutputTime = millis();
        } else {
          _output = false;
        }
      } else {
        _output = false;
      }
    }
};

class DHT_Display {
private:
  DHT dht;
  uint8_t row;
  float lastTemp;
  float lastHum;
  unsigned long lastSampleTime;
  unsigned long lastUpdateTime;
  float tempSum;
  float humSum;
  int sampleCount;

  bool fastMode;
  const unsigned long sampleIntervalSlow = 2500; // 2.5s
  const unsigned long sampleIntervalFast = 1000; // 1s
  const unsigned long updateInterval = 5000;     // 5s
  const float tempThreshold = 3.0;               // ℃
  const float humThreshold  = 20.0;              // %

public:
  DHT_Display(uint8_t pin, uint8_t r) : dht(pin, DHTTYPE), row(r),
                                        lastTemp(NAN), lastHum(NAN),
                                        lastSampleTime(0), lastUpdateTime(0),
                                        tempSum(0), humSum(0), sampleCount(0),
                                        fastMode(false) {}

  void begin() {
    dht.begin();
  }

  // now takes a flag: if showOnOLED==true then draws to OLED; otherwise only samples + Serial
  void update(bool showOnOLED) {
    unsigned long now = millis();

    unsigned long interval = fastMode ? sampleIntervalFast : sampleIntervalSlow;
    if (now - lastSampleTime >= interval) {
      lastSampleTime = now;
      float t = dht.readTemperature();
      float h = dht.readHumidity();
      if (!isnan(t)) tempSum += t;
      if (!isnan(h)) humSum += h;
      sampleCount++;
    }

    if (now - lastUpdateTime >= updateInterval) {
      lastUpdateTime = now;

      float avgTemp = NAN;
      float avgHum  = NAN;

      if (sampleCount > 0) {
        avgTemp = tempSum / sampleCount;
        avgHum  = humSum  / sampleCount;
      }

      char buf[40];
      snprintf(buf, sizeof(buf), "T=%.1f H=%.1f", avgTemp, avgHum);
      Serial.println(buf);

      if (showOnOLED) {
        display(avgTemp, avgHum);
      }

      if (!isnan(avgTemp) && !isnan(avgHum) && !isnan(lastTemp) && !isnan(lastHum)) {
        if (!fastMode) {
          if (abs(avgTemp - lastTemp) > tempThreshold || abs(avgHum - lastHum) > humThreshold) {
            fastMode = true;
          }
        } else {
          if (abs(avgTemp - lastTemp) <= tempThreshold && abs(avgHum - lastHum) <= humThreshold) {
            fastMode = false;
          }
        }
      }

      if (!isnan(avgTemp)) lastTemp = avgTemp;
      if (!isnan(avgHum))  lastHum  = avgHum;

      tempSum = 0;
      humSum = 0;
      sampleCount = 0;
    }
  }

  void display(float temp, float hum) {
    char buffer[32];
    if (isnan(temp)) {
      snprintf(buffer, sizeof(buffer), "T: NaN H: ");
    } else {
      snprintf(buffer, sizeof(buffer), "T: %.1f", temp);
    }
    if (isnan(hum)) {
      strcat(buffer, "NaN%");
    } else {
      char humBuf[16];
      snprintf(humBuf, sizeof(humBuf), " H: %.1f%", hum);
      strcat(buffer, humBuf);
    }
    u8x8.drawString(0, row, buffer);
  }

  void displayLast() {
    display(lastTemp, lastHum);
  }
};
DHT_Display dhtDisplay(DHTPIN, 2);

class WaterController {
private:
  SoilSensor &sensor;
  RTCManager &rtc;
  uint8_t pumpPin;

  float threshold;
  int maxPerWeek;
  int waterCountThisWeek;
  unsigned long lastPumpMillis;
  bool pumping;

  uint8_t lastDOW;
  int lastWaterHour;
  int lastWaterDay;
  int lastWaterMonth;

  unsigned long startTime;
  unsigned long warmUpDuration;

  const unsigned long pumpDuration = 20000;
  const unsigned long minInterval  = 4UL * 3600UL * 1000UL;

public:
  WaterController(SoilSensor &s, RTCManager &r, uint8_t pinPump,
                  float th, int maxW,
                  unsigned long warmUpSec = 10)
      : sensor(s), rtc(r), pumpPin(pinPump),
        threshold(th), maxPerWeek(maxW),
        waterCountThisWeek(0), lastPumpMillis(0),
        pumping(false), lastDOW(255),
        lastWaterHour(-1), lastWaterDay(-1), lastWaterMonth(-1),
        warmUpDuration(warmUpSec * 1000UL)
  {}

  void begin() {
    pinMode(pumpPin, OUTPUT);
    digitalWrite(pumpPin, LOW);
    startTime = millis();
  }

  void update() {
    if (millis() - startTime < warmUpDuration) return;

    Ds1302::DateTime now;
    rtc.getDateTime(now);

    if (now.dow != lastDOW) {
        lastDOW = now.dow;
        if (now.dow == 1) waterCountThisWeek = 0;
    }

    if (pumping) {
        if (millis() - lastPumpMillis >= pumpDuration) stopPump();
        return;
    }

    float moisture = sensor.getLatestMoisture();
    if (isnan(moisture)) return;

    if (moisture > threshold) return;

    if (lastWaterHour >= 0) {
        unsigned long elapsed = millis() - lastPumpMillis;
        if (elapsed < minInterval) return;
    }

    if (waterCountThisWeek >= maxPerWeek) return;

    startPump();
    waterCountThisWeek++;
    lastWaterHour = now.hour;
    lastWaterDay = now.day;
    lastWaterMonth = now.month;

}

  int getWaterCountThisWeek() const { return waterCountThisWeek; }
  int getMaxPerWeek() const { return maxPerWeek; }

private:
  void startPump() {
    pumping = true;
    lastPumpMillis = millis();
    digitalWrite(pumpPin, HIGH);
    Serial.println("Pump START");
  }

  void stopPump() {
    pumping = false;
    digitalWrite(pumpPin, LOW);
    Serial.println("Pump STOP");
  }
};

class MenuSystem {  
public:
  enum Mode {
    MAIN_MENU,
    DATA_MODE,
    SETTIME_MODE,
    TEST2_MODE
  };

private:
  U8X8_SSD1306_128X64_NONAME_HW_I2C &display;
  DHT_Display &dhtDisplay;
  Mode currentMode;
  const char **menuItems;
  int menuSize;
  int cursorIndex;
  uint8_t lastSecond;
  SoilSensor &sensor1;
  SoilSensor &sensor2;
  unsigned long lastSoilUpdate = 0;
  unsigned long lastSoilDisplay = 0;
  WaterController &wc1;
  WaterController &wc2;

public:
  MenuSystem(U8X8_SSD1306_128X64_NONAME_HW_I2C &u8x8,
          DHT_Display &dht,
          const char* items[], int size,
          SoilSensor &s1, SoilSensor &s2,
          WaterController &w1, WaterController &w2)
    : display(u8x8),
      dhtDisplay(dht),
      currentMode(DATA_MODE),
      menuItems(items),
      menuSize(size),
      cursorIndex(0),
      lastSecond(255),
      sensor1(s1), 
      sensor2(s2),
      wc1(w1),
      wc2(w2)
  {}
  void begin() {
    sensor1.begin();
    sensor2.begin();
    if (currentMode == DATA_MODE) {
      drawModeScreen(DATA_MODE);
    } else {
      drawMainMenu();
    }
  }

  void update(bool btn1, bool btn2, bool btn3, bool btn4) {
    switch (currentMode) {
      case MAIN_MENU:
        handleMainMenu(btn1, btn2, btn3);
        break;
      case DATA_MODE:
        handleDataMode(btn4);
        break;
      case SETTIME_MODE:
        handleSetTimeModes(btn1, btn2, btn3, btn4);
        break;
      case TEST2_MODE:
        break;
    }
  }

private:

  Ds1302::DateTime timeSnapshot;
  void drawMainMenu() {
    display.clear();
    display.drawString(0, 0, "   Main Menu");
    for (int i = 0; i < menuSize; i++) {
      char buffer[20];
      snprintf(buffer, sizeof(buffer), "%-12s%s", menuItems[i], 
              (i == cursorIndex) ? "<-" : "");
      display.drawString(0, i + 1, buffer);
    }
  }

  void drawModeScreen(Mode m) {
    display.clear();
    switch (m) {
      case DATA_MODE: display.drawString(0, 0, "      Data"); break;
      case SETTIME_MODE: display.drawString(0, 0, "    Set Time"); break;
      default: break;
    }
  }

  void handleMainMenu(bool btn1, bool btn2, bool btn3) {
    dhtDisplay.update(false);
    Ds1302::DateTime now;
    rtcManager.getDateTime(now);
    char buf[11];
    snprintf(buf, sizeof(buf), "20%02d/%02d/%02d", now.year, now.month, now.day);
    display.drawString(16, 7, buf);

    if (btn2 && cursorIndex > 0) {
      cursorIndex--;
      drawMainMenu();
    }
    if (btn3 && cursorIndex < menuSize - 1) {
      cursorIndex++;
      drawMainMenu();
    }
    if (btn1) {
      switch (cursorIndex) {
        case 0: 
          currentMode = DATA_MODE; 
          break;
        case 1: 
          rtcManager.getDateTime(timeSnapshot);
          currentMode = SETTIME_MODE;
          break;
        case 2: 
          currentMode = TEST2_MODE; 
          break;
      }
      drawModeScreen(currentMode);
    }
  }

  void handleDataMode(bool btn4) {

    char buf[17];
    if (rtcManager.getFormattedMonthDayTime(buf, sizeof(buf))) {
        display.drawString(0, 1, buf);
    }

    dhtDisplay.update(true);
    dhtDisplay.displayLast();

    sensor1.update(true);
    sensor2.update(true);

    sensor1.displayLast();
    sensor2.displayLast();

    char waterInfo1[20];
    char waterInfo2[20];

    snprintf(waterInfo1, sizeof(waterInfo1), "M1: %d (%d 20s)", 
           wc1.getWaterCountThisWeek(), wc1.getMaxPerWeek());
  
    snprintf(waterInfo2, sizeof(waterInfo2), "M2: %d (%d 20s)", 
            wc2.getWaterCountThisWeek(), wc2.getMaxPerWeek());
    
    display.drawString(0, 5, waterInfo1);
    display.drawString(0, 6, waterInfo2);

    if (btn4) {
        currentMode = MAIN_MENU;
        cursorIndex = 0;
        drawMainMenu();
    }
  }

  void handleSetTimeModes(bool btn1, bool btn2, bool btn3, bool btn4) {
    static int editIndex = 0;

    if (btn2 && editIndex > 0) editIndex--;
    if (btn3 && editIndex < 11) editIndex++;

    if (btn1) {
      uint8_t *digits[6] = {
          &timeSnapshot.year, &timeSnapshot.month, &timeSnapshot.day,
          &timeSnapshot.hour, &timeSnapshot.minute, &timeSnapshot.second
      };
      int valueIndex = editIndex / 2;
      int digitPos = editIndex % 2;
      int v = *digits[valueIndex];
      int tens = v / 10;
      int ones = v % 10;

      if (digitPos == 0) tens++;
      else ones++;

      switch (valueIndex) {
        case 0: // year (0~99)
          if (tens > 9) tens = 0;
          if (ones > 9) ones = 0;
          break;
        case 1: // month (1~12)
          {
          int month = tens * 10 + ones;
          if (month > 12) { tens = 0; ones = 1; }  // back to 01
          if (month < 1) { tens = 0; ones = 1; }
          }
          break;
        case 2: // day (1~maxDay)
          {
          int day = tens * 10 + ones;
          int year = timeSnapshot.year + 2000;
          int month = timeSnapshot.month;
          int maxDay = 31;
          if (month == 2) maxDay = (year % 4 == 0 && (year % 100 != 0 || year % 400 == 0)) ? 29 : 28;
          else if (month == 4 || month == 6 || month == 9 || month == 11) maxDay = 30;

          if (day > maxDay) { tens = 0; ones = 1; } 
          if (day < 1) { tens = 0; ones = 1; }
          }
          break;
        case 3: // hour (0~23)
          if (tens * 10 + ones > 23) { tens = 0; ones = 0; }
          break;
        case 4: // minute (0~59)
        case 5: // second (0~59)
          if (tens * 10 + ones > 59) { tens = 0; ones = 0; }
          break;
      }

      *digits[valueIndex] = tens * 10 + ones;
  }

    char bufDate[11], bufTime[9];
    snprintf(bufDate, sizeof(bufDate), "20%02d/%02d/%02d",
             timeSnapshot.year, timeSnapshot.month, timeSnapshot.day);
    snprintf(bufTime, sizeof(bufTime), "%02d:%02d:%02d",
             timeSnapshot.hour, timeSnapshot.minute, timeSnapshot.second);

    display.drawString(0, 1, bufDate);
    display.drawString(0, 2, bufTime);

    if (btn4) {
        rtcManager.setDateTime(timeSnapshot);
        editIndex = 0;
        currentMode = MAIN_MENU;
        cursorIndex = 0;
        drawMainMenu();
    }
  }

};

Button btn1(BUTTON1_PIN, BUTTON_PULSE);
Button btn2(BUTTON2_PIN, BUTTON_PULSE);
Button btn3(BUTTON3_PIN, BUTTON_PULSE);
Button btn4(BUTTON4_PIN, BUTTON_PULSE);

SoilSensor sensor1(PIN_SOILSENSOR_1, 3, u8x8);
SoilSensor sensor2(PIN_SOILSENSOR_2, 4, u8x8);

WaterController wc1(sensor1, rtcManager, PUMP_PIN_1, 20.0, 5, 10);
WaterController wc2(sensor2, rtcManager, PUMP_PIN_2, 30.0, 5, 10);

MenuSystem menu(u8x8, dhtDisplay, menuItems, menuSize, sensor1, sensor2, wc1, wc2);

void clearLine(uint8_t row);

bool pumpState = false;

void setup() {
  Serial.begin(115200);

  Wire.begin(22, 23);  // SDA=22, SCL=23

  u8x8.begin();
  u8x8.setFont(u8x8_font_chroma48medium8_r);
  u8x8.clear();

  sensor1.begin();
  sensor2.begin();
  Serial.println("SoilSensor ready");
  delay(100);

  rtcManager.begin();
  Serial.println("RTC ready");
  delay(100);

  dhtDisplay.begin();
  Serial.println("DTH ready");
  delay(100);

  menu.begin();
  Serial.println("OLED Menu ready");
  delay(100);

  wc1.begin();
  wc2.begin();
  Serial.println("WaterController ready");
  
  Serial.println("All Setup ready");
  delay(1000);
}

void loop() {
  bool b1 = btn1.update();
  bool b2 = btn2.update();
  bool b3 = btn3.update();
  bool b4 = btn4.update();

  menu.update(b1, b2, b3, b4);

  sensor1.update(false);
  sensor2.update(false);

  wc1.update();
  wc2.update();
}



void clearLine(uint8_t row) {
  char empty[LINE_WIDTH + 1];
  memset(empty, ' ', LINE_WIDTH);
  empty[LINE_WIDTH] = '\0';
  u8x8.drawString(0, row, empty);
}

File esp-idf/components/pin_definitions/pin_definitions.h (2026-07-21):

#ifndef PIN_DEFINITIONS_H
#define PIN_DEFINITIONS_H

// ============================================================
//  V2.0 引脚定义 — 植物生长控制器
//  所有 GPIO 分配集中于此文件，main.c 和各模块统一引用
// ============================================================

// ---------- 系统固定引脚（不可更改）----------
#define PIN_UART_TX         1    // UART0 TXD → CH340C RX（固定 strapping）
#define PIN_UART_RX         3    // UART0 RXD → CH340C TX（固定 strapping）
// GPIO0  → 自动下载电路 + BOOT 按键（strapping）
// GPIO2  → 板载 LED 或 strapping（视 PCB 而定）

// ---------- 传感器 ----------
#define PIN_SHT30_SCL           25   // I²C 时钟
#define PIN_SHT30_SDA           26   // I²C 数据
#define PIN_DS18B20_BUS         33   // One Wire 单总线（2 颗 DS18B20 共享）
#define PIN_DS18B20_MAX_COUNT   2    // 冷端 + 热端

#define PIN_MOISTURE_POWER      32   // 土壤湿度传感器 VCC 控制（高电平上电）
#define PIN_MOISTURE_ADC        35   // 土壤湿度模拟输入（ADC1_CH7，仅输入）

#define PIN_FLOAT_SWITCH        21   // 浮球开关数字输入（需外部上拉）

#define PIN_NTC_OVERTEMP        36   // NTC 过温断电电路状态监控（仅输入）
                                     // 比较器输出：高电平=过温，低电平=正常

// ---------- 执行器 - NMOS 数字开关 ----------
#define PIN_VENTILATION_FAN     5    // 通风风扇 SI2302 低端开关
#define PIN_TEC_COLD_FAN        17   // TEC 冷端散热风扇 SI2302 低端开关
#define PIN_IRRIGATION_PUMP     16   // 蠕动泵 SI2302 低端开关

// ---------- 执行器 - PWM ----------
#define PIN_COB_LED_PWM         14   // COB LED 升压恒流驱动 PWM（XL6005E1 EN/DIM）
#define PIN_COB_LED_POWER       12   // COB LED 升压恒流驱动 EN（高电平使能）
#define PIN_WATER_FAN_PWM       18   // 水冷风扇 4 线 PWM 调速
#define PIN_WATER_FAN_TACH      19   // 水冷风扇转速反馈 TACH（可选，脉冲计数）

// ---------- TEC H 桥（Phase 3 实现）----------
#define PIN_TEC_PWM_H           13   // IR2104 #1 高侧 / IR2104 #2 低侧（MCPWM）
#define PIN_TEC_PWM_L           27   // IR2104 #1 低侧 / IR2104 #2 高侧（MCPWM）

// ============================================================
//  注意事项：
//  1. GPIO34~39 为 ESP32 仅输入引脚，已正确分配为输入功能
//  2. GPIO35/36 不能用作 UART TX（无输出能力），UART 使用 GPIO1/3
//  3. GPIO12 为 MTDI strapping，V1.0 用作灌溉，V2.0 已改为 GPIO16
//  4. 所有 NMOS 低端开关需栅极下拉电阻（已由硬件保证）
// ============================================================

#endif // PIN_DEFINITIONS_H

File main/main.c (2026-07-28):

#include "esp_log.h"
#include "freertos/FreeRTOS.h"
#include "freertos/task.h"
#include "driver/gpio.h"
#include "driver/uart.h"
#include "tec_controller.h"
#include "pin_definitions.h"
#include "time_manager.h"
#include "input_parser.h"
#include "command_processor.h"
#include "gpio_control.h"
#include "ventilation_control.h"
#include "light_control.h"
#include "irrigation_controller.h"
#include "moisture_sensor.h"
#include "cloud_comm.h"
#include "ds18b20_sensor.h"
#include "sht30_sensor.h"
#include "float_switch.h"
#include "fan_control.h"
#include "system_monitor.h"
#include "esp_task_wdt.h"
#include "vofa_output.h"
#include "event_bus.h"

static const char *TAG = "MAIN";

static TaskHandle_t s_vofa_task_handle = NULL; 

// ==================== Vofa+ 传感器数据发布任务 ====================
static void vofa_sensor_task(void *arg)
{
   (void)arg;
   esp_task_wdt_add(NULL);
   vTaskDelay(pdMS_TO_TICKS(3000));
   ESP_LOGI(TAG, "Vofa sensor task started");
   while (1) {
      float sht30_t = 0, sht30_h = 0;
      sht30_sensor_get_data(&sht30_t, &sht30_h);
      float ds18_cold = -999, ds18_hot = -999;
      ds18b20_sensor_get_temperature_cached(0, &ds18_cold);   // ← 改用 cached
      ds18b20_sensor_get_temperature_cached(1, &ds18_hot);    // ← 改用 cached
      // 湿度传感器由 irrigation_controller 按需读取，此处不再轮询
      float moist_pct = 0.0f;
      uint32_t moist_mv = 0;
      bool has_water = float_switch_get_state();
      bool ntc_overtemp = (gpio_get_level(PIN_NTC_OVERTEMP) == 1);
      bool light_on = light_control_is_on();
      uint8_t light_duty = light_control_get_pwm_duty();
      bool pump_on = false;
      uint8_t pump_speed = 0;
      vofa_output_send_sensor_frame(sht30_t, sht30_h,
                                    ds18_cold, ds18_hot,
                                    moist_pct, moist_mv,
                                    has_water, ntc_overtemp,
                                    light_duty, light_on,
                                    pump_speed, pump_on);
      esp_task_wdt_reset();                              
      vTaskDelay(pdMS_TO_TICKS(1000));
   }
}

void app_main(void)
{
   ESP_LOGI(TAG, "========================================");
   ESP_LOGI(TAG, "  Plant Grow Controller V2.0 Boot");
   ESP_LOGI(TAG, "========================================");
   esp_log_level_set("*", ESP_LOG_INFO);

   // ---- 基础设施 ----
   ESP_LOGI(TAG, "[0/9] Initializing Event Bus...");
   event_bus_init();

   ESP_LOGI(TAG, "[1/9] Initializing GPIO Control...");
   gpio_control_init();

   ESP_LOGI(TAG, "[2/9] Initializing Vofa+ Output (UART0, 115200bps)...");
   vofa_output_init(UART_NUM_0, 115200);
   vofa_output_subscribe_all();

   ESP_LOGI(TAG, "[3/9] Initializing Time Manager...");
   time_manager_init();

   ESP_LOGI(TAG, "[4/9] Initializing Input Parser (non-blocking)...");
   input_parser_init(false, INPUT_MODE_NON_BLOCKING);

   ESP_LOGI(TAG, "[5/9] Initializing Command Processor...");
   command_processor_init();

   // ---- 传感器 ----
   ESP_LOGI(TAG, "[6/9] Initializing Sensors...");
   moisture_sensor_init(PIN_MOISTURE_POWER, PIN_MOISTURE_ADC);
   ds18b20_sensor_init(PIN_DS18B20_BUS, PIN_DS18B20_MAX_COUNT);
   ds18b20_sensor_start_continuous();
   sht30_sensor_init(PIN_SHT30_SDA, PIN_SHT30_SCL);
   sht30_sensor_start();
   float_switch_init(PIN_FLOAT_SWITCH);
   float_switch_start_monitor(500);

   // ---- 执行器 ----
   ESP_LOGI(TAG, "[7/9] Initializing Actuators...");
   fan_control_init();
   ventilation_control_init(PIN_VENTILATION_FAN);
   ventilation_control_start();

   const int light_pins[LIGHT_CHANNEL_COUNT] = { PIN_COB_LED_PWM };
   light_control_init(light_pins, PIN_COB_LED_POWER);  // 传入电源引脚

   irrigation_controller_init(PIN_IRRIGATION_PUMP);

   // ---- TEC 温度控制 ----
   ESP_LOGI(TAG, "[7.5/9] Initializing TEC Controller...");
   tec_controller_init();

   // ---- 云端通信 ----
   ESP_LOGI(TAG, "[8/9] Initializing Cloud Communication...");
   cloud_comm_init();
   cloud_comm_start();

   // ---- 系统监控 ----
   ESP_LOGI(TAG, "[9/9] Initializing System Monitor...");
   system_monitor_init(10000, 256);

   // ---- Vofa+ 数据任务 ----
   xTaskCreate(vofa_sensor_task, "vofa_sensor", 4096, NULL,
               tskIDLE_PRIORITY + 3, &s_vofa_task_handle);
   if (s_vofa_task_handle) {
      system_monitor_register_task("vofa_sensor", s_vofa_task_handle);
   }

   ESP_LOGI(TAG, "========================================");
   ESP_LOGI(TAG, "  All components initialized.");
   ESP_LOGI(TAG, "  Ready. Type 'help' for commands.");
   ESP_LOGI(TAG, "========================================");

   while (1) {
      input_parser_poll();
      light_control_poll();
      irrigation_controller_poll();

      if (input_parser_frame_ready()) {
         const char *frame = input_parser_get_frame();
         if (frame != NULL) {
            command_processor_process_frame(frame);
         }
      }

      system_monitor_feed_watchdog();
      vTaskDelay(50 / portTICK_PERIOD_MS);
   }
}

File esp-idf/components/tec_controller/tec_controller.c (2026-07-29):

#include "tec_controller.h"
#include "esp_log.h"
#include "esp_timer.h"
#include "freertos/FreeRTOS.h"
#include "freertos/task.h"
#include "freertos/timers.h"
#include "freertos/semphr.h"
#include "esp_task_wdt.h"
#include "driver/mcpwm.h"
#include "driver/gpio.h"
#include "nvs_flash.h"
#include "nvs.h"
#include <math.h>
#include <string.h>
#include <stdlib.h>
#include "pin_definitions.h"
#include "fan_control.h"
#include "sht30_sensor.h"
#include "ds18b20_sensor.h"
#include "ventilation_control.h"
#include "event_bus.h"
#include "data_processor.h"
#include "vofa_output.h"

/* ================================================================
 *  配置宏
 * ================================================================ */
#define TEC_PWM_FREQ_HZ           20000   /* MCPWM 载波频率 20 kHz */
#define TEC_PWM_UNIT              MCPWM_UNIT_0
#define TEC_PWM_TIMER             MCPWM_TIMER_0
#define TEC_TASK_INTERVAL_MS      1000    /* 控制任务周期 1 Hz */
#define TEC_PI_INTERVAL_SEC       5       /* PI 运算间隔 5 秒 */
#define TEC_IDENT_COARSE_STEP     5.0f    /* 粗标定步长 (%) */
#define TEC_IDENT_FINE_STEP       1.0f    /* 精标定步长 (%) */
#define TEC_SAFE_TEMP_LIMIT       58.0f   /* 散热器安全上限 (℃) */
#define TEC_ATTEN_START_TEMP      55.0f   /* 开始线性衰减的温度 */
#define TEC_ATTEN_END_TEMP        60.0f   /* 完全衰减到 0 的温度 */
#define TEC_STEADY_STDDEV_PCT     0.5f    /* 稳态判据：标准差 < 0.5% */
#define TEC_STEADY_MIN_SAMPLES    30      /* 至少 30 个样本 (30 秒) */
#define TEC_STEADY_MAX_WAIT_SEC   1800    /* 最大等待 30 分钟（超时放松阈值） */
#define TEC_COOLDOWN_MAX_WAIT_SEC 1200    /* 回温最大等待 20 分钟 */
#define TEC_TEMP_RATE_THRESHOLD   0.0083f /* 0.5°C/min ≈ 0.0083°C/s */
#define TEC_MA_FILTER_LEN         10      /* 移动平均窗口 */
#define TEC_SENSOR_OFFLINE_THRESHOLD  5    /* 连续 5 秒无有效数据 → 视为硬件故障 */
#define TEC_NVS_NAMESPACE  "tec_ctrl"
#define TEC_NVS_KEY        "ident"
#define TEC_IDENT_MIN_STEP_DWELL_SEC  60    /* 每步最少等待 60 秒（给热传递留时间） */
#define TEC_IDENT_MIN_DT              0.2f  /* 温度响应阈值：至少变化 0.2°C 才认为系统有响应 */

#define TAG "TEC_CTRL"

#define TEC_LOGI(fmt, ...) ESP_LOGI(TAG, fmt, ##__VA_ARGS__)
#define TEC_LOGW(fmt, ...) ESP_LOGW(TAG, fmt, ##__VA_ARGS__)
#define TEC_LOGE(fmt, ...) ESP_LOGE(TAG, fmt, ##__VA_ARGS__)

/* ================================================================
 *  移动平均滤波器
 * ================================================================ */
typedef struct {
   float buf[TEC_MA_FILTER_LEN];
   int   idx;
   int   count;
   float sum;
} ma_filter_t;

static void ma_init(ma_filter_t *f) {
   memset(f, 0, sizeof(*f));
}

static void ma_push(ma_filter_t *f, float v) {
   if (f->count < TEC_MA_FILTER_LEN) {
      f->buf[f->count++] = v;
      f->sum += v;
   } else {
      f->sum -= f->buf[f->idx];
      f->buf[f->idx] = v;
      f->sum += v;
      f->idx = (f->idx + 1) % TEC_MA_FILTER_LEN;
   }
}

static float ma_value(const ma_filter_t *f) {
   if (f->count == 0) return 0.0f;
   return f->sum / (float)f->count;
}

static bool ma_ready(const ma_filter_t *f) {
   return f->count >= TEC_MA_FILTER_LEN / 2;
}

/* ================================================================
 *  全局状态
 * ================================================================ */
static tec_state_t          s_state = TEC_STATE_OFF;
static float                s_duty = 50.0f;       /* 当前占空比 */
static float                s_target_temp = 25.0f;
static tec_ident_result_t   s_ident;
static TaskHandle_t         s_task_handle = NULL;
static SemaphoreHandle_t    s_mutex = NULL;

/* 传感器连续离线计数器（用于短时故障容忍） */
static int s_sht30_offline_cnt = 0;
static int s_ds18_offline_cnt[2] = {0, 0};

/* 传感器缓存（由控制任务每秒更新） */
static float s_sht30_temp = 0.0f;
static float s_id_step_start_temp[2] = {0.0f, 0.0f};  /* 当前步起始时两个 DS18B20 的温度 */
static float s_ds18_temp[2] = {0.0f, 0.0f};
static bool  s_sht30_valid = false;
static bool  s_ds18_valid[2] = {false, false};

/* PI 控制器状态 */
static float s_pi_integral = 0.0f;
static int   s_pi_tick_counter = 0;
static bool  s_pi_enabled = false;

/* 辨识过程状态机 */
typedef enum {
   IDSUB_IDLE = 0,
   /* --- 阶段 1：散热器极限 --- */
   IDSUB_H1_STABILIZE,        /* u=0 等待稳定 */
   IDSUB_H2_COARSE_FWD,       /* 粗标正向 */
   IDSUB_H3_FINE_FWD,         /* 精标正向 → u_heat_max */
   IDSUB_H4_DETERMINE_SIDE,   /* 判定冷热端 */
   IDSUB_H5_COOLDOWN,         /* 回温到环境 */
   IDSUB_H6_COARSE_REV,       /* 粗标反向 */
   IDSUB_H7_FINE_REV,         /* 精标反向 → u_cool_max */
   /* --- 阶段 2：系统模型 --- */
   IDSUB_S1_STABILIZE_AMB,    /* u=0 记录 T_amb */
   IDSUB_S2_STEP_COOL,        /* 阶跃制冷 */
   IDSUB_S3_COOLDOWN2,        /* 回温 */
   IDSUB_S4_STEP_HEAT,        /* 阶跃制热 */
   IDSUB_S5_FIT_MODEL,        /* 拟合 FOPDT → PI 参数 */
   IDSUB_DONE,
} ident_substate_t;
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

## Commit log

2025-11-17 Update button, still have problem with pulse button. Skip it for oled first
    [main.cpp]
2025-11-17 Backup of button code
2025-11-17 Update DTH, button code ok, esp32 pin2 broken. oled display normally
    [main.cpp]
2025-11-17 Add menu. with four buttons to control. Have data page.
2025-11-17 Still have problem with RTC, change another lib
    [main.cpp]
2025-11-17 Correct display version. Still have problem in DTH11 display, seems like fresh rate problem
    [main.cpp]
2025-11-19 Work voltage display soil moisture sensor
2025-11-19 Version that relay and pump work well, which is control by extra button(5) now
2026-02-04 Update command_processor and input_parser Next version add comfirm input for new frame and will set time limit to 15s
2026-02-04 Add time limit for new frame input comfirm input.
2026-02-04 Test for new input module(input parased and command processor). for new frame input check
2026-02-04 Countinue modifying command processor program. Add premodule list display while initializing. Add help command to display available premodule list. Add module + status to check module status and imme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
2026-02-04 Finished GPIO test, have to reset all GPIO first. After reset, now GPIO 1,2,3,4,5,6,7,8,9,14,15,18 all work normally
    [gpio_test.c]
2026-02-05 Finished gpio control block test, now we can only use gpio_control_set level to control the setup GPIO pin level
2026-02-05 Update Offline Time block, include correct time calculation. Leave port for furture online time update. Create program for debug, Now can change time by input correct command
    [main.c, ventilation_control.c]
2026-02-05 Finished PWM test For 20Khz, the resolution can only be 11 bit. For 19Khz, the resolution can be 20 bit.
2026-02-06 Finished PWM test Test for 6 mins, find obvious light became brighter to max. Then turned darker to off.
2026-02-06 Fix module list multiple pin do not display problem
    [command_processor.c, light_control.c]
2026-02-08 Test for ESP32-D chip, with Xetena chip. Have to active BOYA function and reset pins. cannot active such as pin 1, etc..
2026-02-09 Test Version for ESP32-board will actually use for furture. ESP32C6 just for coding.
2026-02-11 First version of irrigation controller block, still have problem in week in irrigation number reset. also have problem in auto irrigation, seems like problem is related in time manager block. The aut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
    [command_processor.c, gpio_control.c, irrigation_controller.c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]
2026-02-11 debuging, still have problem in irrigation controller block
    [command_processor.c, irrigation_controller.c]
2026-02-12 Add moisture sensor. But have 200-500mV difference when using oscilloscope to comfirm the value..
2026-02-15 Add moisture sensor block. Test normal, use efuse calration and two points calbration.
2026-02-15 Success connect irrigation controller and moisture sensor together. Remove manual irrigation. But still need moisture sensor work after calibration
2026-02-16 Change pin default setting Move irrigation controller default pin to GPIO 18 Move light control default pin to GPIO 9, 14 Move moisture sensor pin to 2, 15
2026-02-16 Add cloud comm block Now we can connect to the service and correctly response. But we now do not have any messages in app.
    [main.c]
2026-02-17 Success have all block MQTT upload and display in App Still have problems in message sending, need to transfer multiple line messages into one line.
    [command_processor.c, gpio_control.c, irrigation_controller.c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]
2026-03-14 Adjust MQTT keepalive from 10s to 60s, to avoid mqtt connection failed, which reported ping response failed.
    [irrigation_controller.c]
2026-04-09 Revise README with current project status and features
    Updated the README with new project details and progress.
2026-04-14 Remove control pin in light control, now only pwm control. Update useful pin, ready for 4-channel update
2026-07-02 Reupdate files since the former git is broken
    [command_processor.c, ds18b20_sensor.c]
2026-07-02 Add sht30 sensor for temp and humdity detected.
2026-07-02 Changed ds18b20 sensor reading mode, the reading time decrease from 1220ms to 420ms
2026-07-11 Remove unused GPIO pin definitions for moisture sensor and control components
2026-07-20 Refactor ventilation control and integrate fan control
    - Updated CMakeLists.txt in ventilation_control to require fan_control instead of gpio_control and cloud_comm.
    - Refactored ventilation_control.c to remove gpio_control and cloud_comm dependencies, replacing them with fan_control functions for managing the ventilation fan.
    - Modified main CMakeLists.txt to include fan_control and other necessary components.
    - Enhanced main.c to initialize fan_control and integrate it with the ventilation control logic.
    - Introduced event_bus component for managing event subscriptions and notifications.
    - Added fan_control component for managing different types of fans with PWM and digital control.
    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
2026-07-21 feat(light_control): update initialization to include power pin and add ramp control functions
    feat(moisture_sensor): implement stable reading function for humidity with power management
    fix(pin_definitions): add power pin definition for COB LED driver
    refactor(main): adjust light control initialization to use power pin and remove unnecessary moisture sensor polling
    feat(tls_config): add TLS configuration for MQTT broker with server certificate
    [command_processor.c, irrigation_controller.c, light_control.c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]
2026-07-22 Add TEC controller header file with API definitions and state management
    - Introduced `tec_controller.h` for the TEC temperature controller.
    - Defined states for the controller operation, including initialization, identification, tuning, and manual modes.
    - Added structures for identification results and public API functions for initialization, state retrieval, emergency stop, and manual duty setting.
    - Included necessary includes for standard types and boolean operations.
2026-07-22 delet hmi_uart and changed logic of determine sensor outline and the process of system identification
2026-09-07 git update for solving git problem, reupdate the files
    [Block_Assemb.SLDASM, Connector.SLDPRT, Connector.STL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]
